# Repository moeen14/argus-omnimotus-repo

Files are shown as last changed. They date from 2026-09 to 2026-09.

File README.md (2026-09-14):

# Argus Omnimotus

Argus Omnimotus is an open-source, modular agricultural robot for autonomy research and robotics education. The platform combines four-wheel independent swerve drive, distributed ESP32 control, multimodal sensing, interchangeable edge computers, and configurable manipulation in a sense-plan-act-verify architecture.

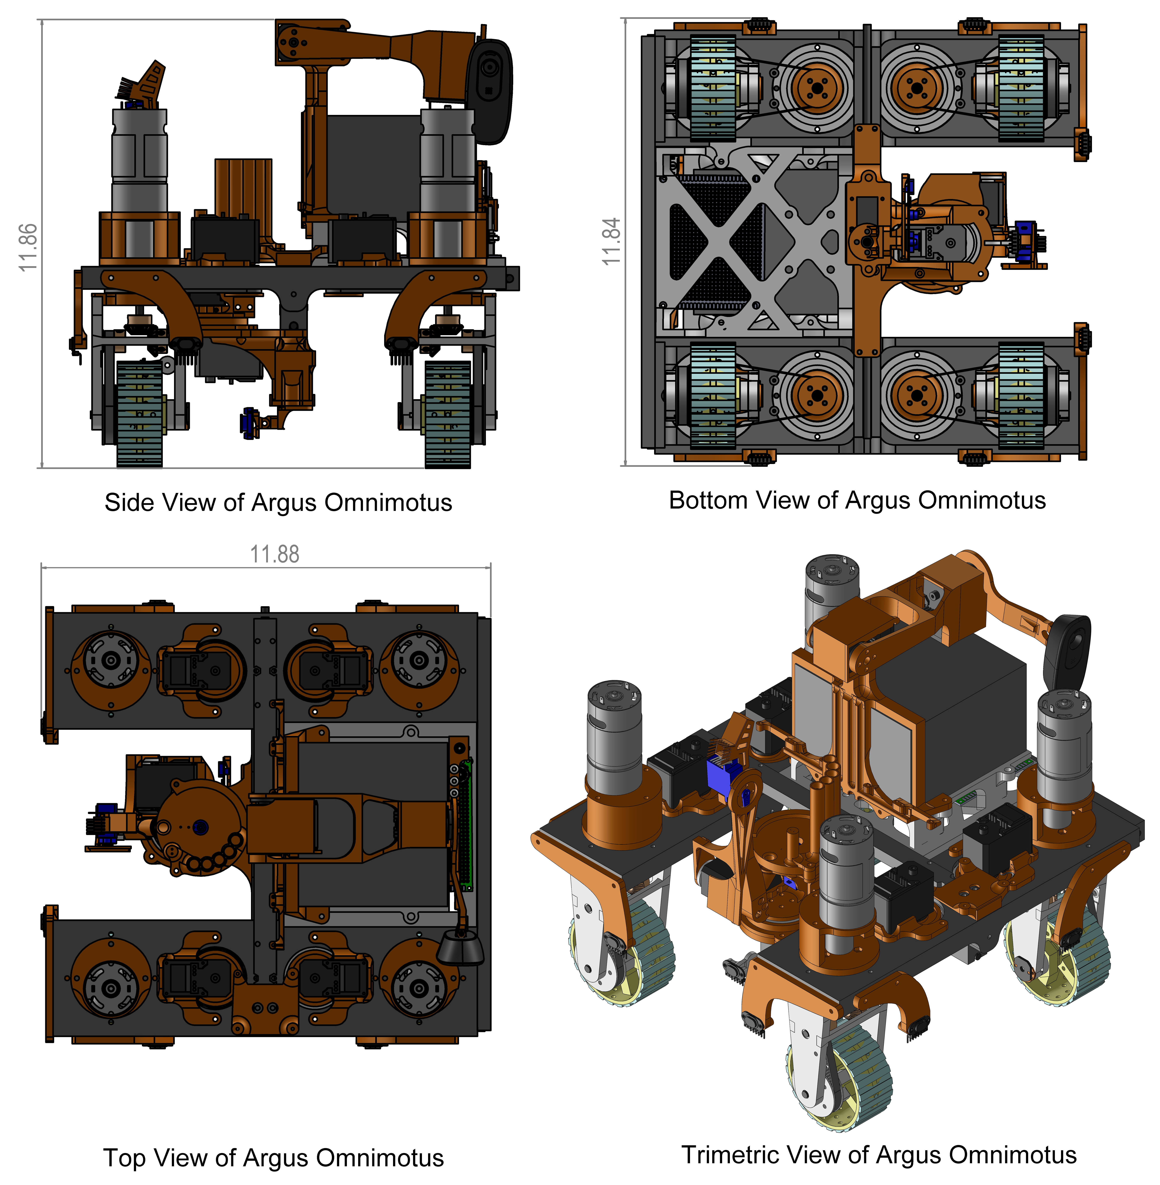
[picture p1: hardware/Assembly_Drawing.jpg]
Argus Omnimotus assembly views


## Repository structure

```text
argus-omnimotus-repo/
|-- applications/   Five complete robot applications
|-- tuning/         Isolated hardware and controller tests
|-- firmware/       ESP32 sensor-board and motion-board firmware
|-- hardware/       CAD, assembly drawing, circuit diagram, BOM and pin map
|-- vision/         Standalone Jetson vision programs
|-- deployment/     Pi 5, Hailo-8 and Jetson deployment tools
|-- models/         Model manifest and Hugging Face download/build utility
|-- docs/           Setup, operation and protocol documentation
|-- tools/          Application, firmware and model launchers
`-- tests/          Hardware-independent repository tests
```

## Main applications

| Command | Program | Purpose |
|---|---|---|
| `dashboard` | `applications/operator_dashboard.py` | Operator dashboard, manual control and telemetry |
| `identify` | `applications/crop_identification.py` | Bottom-camera crop and platform identification |
| `navigate` | `applications/navigate_testbed.py` | Testbed navigation without crop actuation |
| `field` | `applications/field_tasks.py` | Full-field navigation and actuation |
| `lane` | `applications/single_lane_tasks.py` | Repeated navigation and tasks on one lane |

The complete application guide, including optional task verification, is in [docs/programs.md](docs/programs.md). Component-level programs are listed in [tuning/README.md](tuning/README.md).

## Build and run

1. Review the [hardware files](hardware/README.md) and assemble the platform.
2. Build and flash both ESP32 boards using [docs/firmware.md](docs/firmware.md).
3. Configure the Jetson using [docs/jetson-setup.md](docs/jetson-setup.md).
4. Obtain the ONNX weights using [models/README.md](models/README.md), then build TensorRT engines on the Jetson.
5. Copy and edit the robot configuration, complete [calibration](docs/bring-up.md), and launch an application.

```bash
cp robot.example.json robot.json
python tools/run.py --dry-run dashboard
python tools/run.py dashboard
```

The software defaults match the original platform. Confirm device paths, steering angles, wheel directions, camera geometry, controller gains, and mission settings before operating another build.

## Vision deployment

| Target | Backend | Guide |
|---|---|---|
| Raspberry Pi 5 | NCNN | [deployment/raspberry-pi-5.md](deployment/raspberry-pi-5.md) |
| Raspberry Pi 5 with Hailo-8 | HailoRT | [deployment/raspberry-pi-5-hailo8.md](deployment/raspberry-pi-5-hailo8.md) |
| Jetson Orin Nano | TensorRT | [deployment/jetson-orin-nano.md](deployment/jetson-orin-nano.md) |

These targets share the inference evaluator in `deployment/tools/`. The complete autonomous robot applications use the Jetson TensorRT/CUDA implementation. Download the [vision models](https://huggingface.co/moeen14/argus-omnimotus-vision-models) and [labeled evaluation dataset](https://huggingface.co/datasets/moeen14/argus-omnimotus-vision-dataset) from Hugging Face.

## Citation

Please cite the project using [CITATION.cff](CITATION.cff). Contributions are described in [CONTRIBUTING.md](CONTRIBUTING.md).

## License

Argus Omnimotus is released under the [MIT License](LICENSE).

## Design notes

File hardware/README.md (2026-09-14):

# Hardware

This directory contains the mechanical model, assembly drawing, system circuit diagram, component list, and firmware-derived ESP32 pin assignments.

## Files

| File | Description |
|---|---|
| [Argus_Omnimotus_Master_Multibody.SLDPRT](Argus_Omnimotus_Master_Multibody.SLDPRT) | Editable SolidWorks multibody CAD model |
| [Assembly_Drawing.jpg](Assembly_Drawing.jpg) | Side, bottom, top, and trimetric assembly views |
| [Circuit_Diagram.png](Circuit_Diagram.png) | Computing, sensing, actuation, communication, and power architecture |
| [BOM.csv](BOM.csv) | Machine-readable component list |
| [Pin_Map.md](Pin_Map.md) | GPIO, bus, address, and servo-ID assignments from the firmware |

## Assembly drawing

Argus Omnimotus assembly drawing

## Circuit diagram

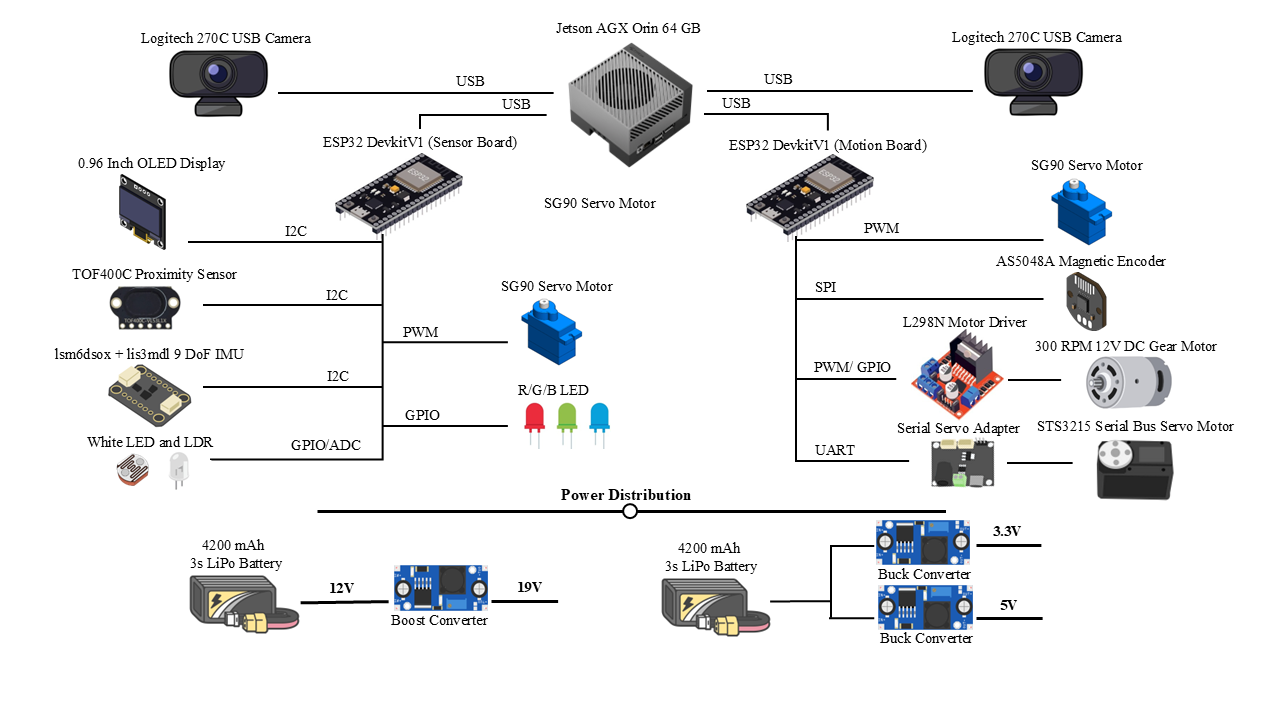
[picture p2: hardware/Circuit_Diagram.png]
Argus Omnimotus circuit diagram


The circuit diagram presents the system-level connections. Use [Pin_Map.md](Pin_Map.md) and the two sketches in [`firmware/`](../firmware/) for implemented GPIO assignments and serial commands. Board 01 handles the wheel encoders in the released firmware, while Board 02 handles the dispenser LDR.

The chassis is primarily 3D-printed PLA reinforced by two 5 mm steel rods. Open the `.SLDPRT` file in SolidWorks to access the editable bodies. The CAD file is stored using Git LFS.

[Return to repository overview](../README.md)

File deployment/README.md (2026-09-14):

# Choose a deployment target

| Target | Vision backend | Start here |
|---|---|---|
| Raspberry Pi 5 CPU | NCNN `.param` + `.bin` | [Pi 5](raspberry-pi-5.md) |
| Raspberry Pi 5 + Hailo-8 | HailoRT `.hef` | [Pi 5 + Hailo-8](raspberry-pi-5-hailo8.md) |
| Jetson Orin Nano | TensorRT `.engine` | [Orin Nano](jetson-orin-nano.md) |

All three use `launch_vision.py` and the shared evaluator. It runs inference on labeled dataset images and writes metrics. Individual live-camera TensorRT utilities are in [vision](../vision/README.md).

The five robot applications use the [robot launcher](../docs/programs.md). Dashboard control uses serial, Tkinter and OpenCV; identification and autonomous applications use TensorRT/PyCUDA. The Pi and Hailo paths provide vision evaluation, while full autonomous control uses the Jetson implementation.

[Model weights](https://huggingface.co/moeen14/argus-omnimotus-vision-models) and the [labeled evaluation dataset](https://huggingface.co/datasets/moeen14/argus-omnimotus-vision-dataset) are distributed through Hugging Face. Keep benchmark assets separate from runtime assets: the benchmark crop model has three classes, while the robot crop model has four.

[Repository home](../README.md)

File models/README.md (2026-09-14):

# Vision assets

[Repository home](../README.md) · [Vision deployment](../deployment/README.md)

Model binaries are distributed through the [Argus Omnimotus model repository](https://huggingface.co/moeen14/argus-omnimotus-vision-models). The [labeled evaluation dataset](https://huggingface.co/datasets/moeen14/argus-omnimotus-vision-dataset) is available separately. This directory contains the SHA-256 and size manifest for the six ONNX files used by the project. Download the files into this directory before verification and engine building.

```bash
python -m pip install -r requirements-models.txt
python tools/models.py download --repo-id moeen14/argus-omnimotus-vision-models --revision main
python tools/models.py verify
python tools/models.py build
```

The download command checks every file against `manifest.json`. `build` runs `trtexec --fp16` on the target Jetson. Use `--directory` for another asset folder and set the same folder in `robot.json`. Repeat `--model FILENAME.onnx` to select individual models.

| ONNX file | Role |
|---|---|
| `crop_detector.onnx` | Bottom-camera crop/platform identification |
| `highcam_platform.onnx` | Overhead platform/ball verification |
| `highcam_rail.onnx` | Current rail segmentation and BEV lane following |
| `lanesegyv8.onnx` | Earlier lane segmentation utilities |
| `resnet18_image_encoder.onnx` | Optional NanoSAM image encoder |
| `mobile_sam_mask_decoder.onnx` | Optional NanoSAM decoder, kept as ONNX |

The field task needs rail and crop engines, plus the overhead platform engine when `--verification on` is selected. NanoSAM is optional. The decoder is excluded from TensorRT building because the existing NanoSAM script runs it with ONNX Runtime. TensorRT engines depend on the target environment; see [NVIDIA's compatibility documentation](https://docs.nvidia.com/deeplearning/tensorrt/latest/getting-started/support-matrix.html). Engine builds and inference must be verified on the target Jetson.

The runtime crop detector uses four classes: `gCrop`, `platform`, `ycrop`, `servo`. The overhead detector uses `ball`, `gcrop`, `platform`, `ycrop`. The separate edge benchmark export declares only three crop-detector classes. Do not substitute benchmark models for robot models based on matching filenames.

The Hugging Face model and dataset cards document class order, preprocessing, release contents, scope, attribution, and licensing. Model downloads use the [Hugging Face Hub API](https://huggingface.co/docs/huggingface_hub/guides/download).

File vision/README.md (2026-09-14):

# Vision utilities

Standalone camera tools are separate from the five robot applications. Launch these through `tools/run.py` so model filenames resolve in the configured model folder:

```bash
python tools/run.py vision/crop_detector_cli.py
python tools/run.py vision/platform_detector_cli.py
python tools/run.py vision/rail_detector.py
```

These use the Jetson TensorRT/PyCUDA environment. `rail_detector_cu.py` is the CuPy variant; `nanosam_cli.py` uses an encoder engine and ONNX decoder. Earlier lane utilities and the distinct crop detector variant remain available for reproduction.

[Model downloads and builds](../models/README.md) | [Pi 5 / Hailo-8 / Orin Nano deployment](../deployment/README.md) | [Main applications](../docs/programs.md)

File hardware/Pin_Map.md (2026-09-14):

# Firmware-derived wiring reference

[Hardware overview](README.md) · [Firmware setup](../docs/firmware.md)

This pin map is extracted from the released firmware. All numbers below are ESP32 GPIO numbers, not DevKit header positions.

## Board 01: sensors

| Interface | GPIO / address |
|---|---|
| Shared I2C | SDA 21, SCL 22, 100 kHz |
| Encoder SPI | SCK 18, MISO 19, MOSI 23 |
| Encoder chip selects, BR / FR / BL / FL | 5 / 4 / 33 / 32 |
| ToF XSHUT, FRS / BRS / BLS / FLF / FLS / CAM / FRF | 13 / 14 / 16 / 17 / 25 / 26 / 27 |
| Corresponding ToF I2C addresses | 0x30 / 0x31 / 0x32 / 0x33 / 0x34 / 0x35 / 0x36 |
| Distal SG90 | 15; 50 Hz, 500–2500 μs; initial angle 180° |
| OLED | I2C, 0x3C, 128 × 64 |
| LSM6DSOX and LIS3MDL | Shared I2C bus |

`CAM` is the firmware's ToF channel label. It is not a camera data connection. Both USB cameras connect directly to the Jetson.

## Board 02: actuators

| Interface | GPIO |
|---|---|
| Bus-servo UART2 | RX 16, TX 17; connect through the appropriate bus-servo interface |
| L298N 1 IN1 / IN2 / IN3 / IN4 | 32 / 33 / 13 / 14 |
| L298N 1 ENA / ENB | 25 / 26 |
| L298N 2 IN1 / IN2 / IN3 / IN4 | 4 / 5 / 18 / 19 |
| L298N 2 ENA / ENB | 21 / 22 |
| RGB red / green / blue | 23 / 15 / 2 |
| Dispenser SG90 | 27 |
| Dispenser LDR | 35 |

Drive PWM is 1 kHz, 8-bit. Motors and serial motion commands use BR, FR, BL, FL order. Bus-servo IDs map as follows:

| ID | Mechanism |
|---|---|
| 1 / 2 / 3 / 4 | BR / FR / FL / BL wheel steering |
| 5 / 6 | Horizontal / vertical arm motion |
| 7 | Bottom camera |
| 8 / 9 | Overhead camera pan / height |

The original deployment note counted only IDs 5–9; the firmware controls **nine** bus servos. GPIO 15 appears on both boards for different functions; that is not a same-board conflict.

The released firmware assigns the **wheel encoders to Board 01** and the **dispenser LDR to Board 02**. These firmware assignments govern the GPIO connections.

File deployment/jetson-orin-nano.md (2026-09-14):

# Jetson Orin Nano

Install the board firmware and JetPack using [NVIDIA's Orin Nano setup guide](https://developer.nvidia.com/embedded/learn/jetson-orin-nano-devkit-user-guide/software_setup.html). For this source, use a JetPack 6 / TensorRT 10 environment compatible with the [recorded Jetson stack](../docs/jetson-setup.md), rather than assuming the newest major release preserves its APIs.

Follow the Python, serial, and camera setup in that guide. Build TensorRT engines on the target Nano and check memory use and control-loop timing before driving.

## Robot applications

```bash
python tools/models.py verify
python tools/models.py build --model crop_detector.onnx --model highcam_rail.onnx --model highcam_platform.onnx
python tools/run.py --dry-run dashboard
python tools/run.py dashboard
```

Supply the ONNX files first using the [model download guide](../models/README.md). Finish [bring-up and calibration](../docs/bring-up.md) before launching `navigate`, `field` or `lane`. Run only one serial-owning application at a time.

## Vision evaluation

Use the **benchmark** ONNX export and dataset, not the robot crop-model manifest. Create an FP16 engine on the Nano:

```bash
/usr/src/tensorrt/bin/trtexec --onnx=/path/to/platform.onnx --saveEngine=/path/to/platform.engine --fp16
python deployment/launch_vision.py orin-nano --check
python deployment/launch_vision.py orin-nano --model /path/to/platform.engine --data /path/to/platform-dataset --task highcam_platform --onnx-ref /path/to/platform.onnx
```

The evaluator additionally uses `onnx` for model metadata. Optional INT8 calibration is in `deployment/tools/build_tensorrt.py`. Build engines on the target device because serialized TensorRT engines are environment-specific.

[Deployment targets](README.md)

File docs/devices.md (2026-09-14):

# Stable serial and camera names

Use `/dev/serial/by-id` and `/dev/v4l/by-id` paths in `robot.json` where available. Identify boards one at a time so sensor and actuator assignments are unambiguous.

If both ESP32 USB adapters report the same serial number, inspect physical connection attributes:

```bash
udevadm info --attribute-walk --name=/dev/ttyUSB0
udevadm info --attribute-walk --name=/dev/ttyUSB1
```

Create `/etc/udev/rules.d/99-argus-esp32.rules` using the actual `KERNELS` USB topology value associated with each adapter. The following is a template, not an installable rule until the placeholders are replaced:

```text
SUBSYSTEM=="tty", KERNELS=="SENSOR_USB_PATH", ATTRS{idVendor}=="10c4", ATTRS{idProduct}=="ea60", SYMLINK+="esp32_01"
SUBSYSTEM=="tty", KERNELS=="ACTUATOR_USB_PATH", ATTRS{idVendor}=="10c4", ATTRS{idProduct}=="ea60", SYMLINK+="esp32_02"
```

The VID/PID above are from the exported robot's CP210x adapters; check yours. Reload with `sudo udevadm control --reload-rules`, then reconnect the boards. Topology aliases change meaning if cables move between hub ports. Confirm identities before enabling actuator power.

[Jetson setup](jetson-setup.md) | [Wiring](../hardware/Pin_Map.md)

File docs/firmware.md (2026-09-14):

# ESP32 DevKit firmware

[Repository home](../README.md) | [Wiring reference](../hardware/Pin_Map.md)

The build target is the classic ESP32 DevKit (`esp32:esp32:esp32`, Arduino's ESP32 Dev Module profile). Confirm flash/board settings for your specific DevKit; ESP32-S3/C3 are different targets.

Install [Arduino CLI](https://arduino.github.io/arduino-cli/) and Python 3.10 or later. From the repository root:

```bash
python tools/firmware.py install
python tools/firmware.py compile
arduino-cli board list
python tools/firmware.py upload --board board01 --port /dev/ttyUSB0
python tools/firmware.py upload --board board02 --port /dev/ttyUSB1
```

Substitute the actual ports, such as `COM5` on Windows. Close serial monitors and control programs before uploading. Uploading compiles first and requires an explicit board and port; it never guesses which board to flash. Each sketch can also be opened in Arduino IDE from its same-named directory.

Core and library versions are defined in `tools/firmware.py`: ESP32 core 3.3.0; ESP32Servo 3.0.9; VL53L1X 1.3.1; Adafruit LSM6DS 4.7.4, LIS3MDL 1.2.4, Unified Sensor 1.1.15, SSD1306 2.5.15, GFX 1.12.6 and BusIO 1.17.4; and SCServo 1.0.2.

Board 02 uses the pin-based LEDC API introduced in [Arduino ESP32 3.x](https://docs.espressif.com/projects/arduino-esp32/en/latest/migration_guides/2.x_to_3.0.html). Core 2.x is unsuitable without porting those calls.

Board 01 identifies as `board01_final_v4`; Board 02 as `board02_final_v10`. Serial communication is newline-terminated ASCII at 921600 baud. See [protocol](protocol.md) and [calibration](bring-up.md).

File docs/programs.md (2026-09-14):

# Main applications

Run commands from the repository root after completing [setup](jetson-setup.md), [model deployment](../models/README.md), and [calibration](bring-up.md). Edit `robot.json` first. Launcher options go before the application name.

| Application | Launch command | Original source |
|---|---|---|
| Operator dashboard | `python tools/run.py dashboard` | `robot/main.py` |
| Crop identification | `python tools/run.py identify` | `robot/identification.py` |
| Navigation without crop tasks | `python tools/run.py navigate` | `Tests/navigation_test.py` |
| Full-field navigation and tasks | `python tools/run.py field` | `Tests/main_task.py` |
| Repeated single-lane tasks | `python tools/run.py lane` | `Tests/lane_platform_alignment_test.py` |

The five primary programs are located directly in `applications/` with names that describe their roles.

## Optional field verification

```bash
python tools/run.py --verification on field
python tools/run.py --verification off field
python tools/run.py --dry-run --verification on field
```

Verification means the existing camera-based ball-placement check after dispensing, including its camera repositioning and retry behavior. It does not disable or enable every sensor feedback check in the controller. The original default remains **off**. When off, the verification TensorRT engine is not loaded; rail and crop engines are still required. The switch applies only to `field` and its compatibility alias `autonomy`.

You can also set `ASABE_ENABLE_BALL_VERIFY` to `1` or `0` in the config's environment dictionary. The command-line flag overrides that setting. `autonomy` remains an alias for `field` so older commands still work.

## Before motion

The dashboard is a local Tkinter interface; the identification and autonomous programs use camera windows and TensorRT. Applications can reposition mechanisms at startup. Run only one application owning the serial ports at a time. Navigation without crop actuation still steers wheels and positions cameras.

Use a dry run to inspect configuration without opening hardware. Test a short controlled sequence after calibration before a complete field run. Mission geometry and controller gains remain in the application source; the launcher does not make the original testbed parameters universal.

[Component tuning](../tuning/README.md) ? [Vision deployment](../deployment/README.md) ? [Repository home](../README.md)

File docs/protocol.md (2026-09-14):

# Serial protocol

[Firmware](firmware.md) | [Wiring](../hardware/Pin_Map.md)

Each board uses USB serial at 921600 baud. Send ASCII commands terminated by a newline. Responses, telemetry and asynchronous completion messages may interleave; clients must parse records rather than assume the next line answers the last command. The sketches remain the complete protocol specification.

## Board 01

Streams `RPM`, `TOF` and `IMU` records. Startup/status messages include firmware and sensor initialization state. OLED commands include `I`, `T`, `T0`, `G`, `B`, `R` and `Z`; `F` resets ToF initialization. `SG90,<angle>` positions the board's SG90. Use the dashboard's existing parser and message handling as the reference client.

## Board 02

| Command | Meaning |
|---|---|
| `P` | Request `POS` for servos 1–9 |
| `MODE,initial,BR,FR,BL,FL` | Apply explicit steering targets; mode may also be `mid` or `perpendicular` |
| `I`, `M`, `T` | Legacy initial, mid, perpendicular presets |
| `F<pwm>`, `B<pwm>` | Forward/reverse in initial mode |
| `L<pwm>`, `R<pwm>` | Lateral movement in perpendicular mode |
| `CW<pwm>`, `CCW<pwm>` | Rotation in mid mode |
| `Fbr,fr,bl,fl` and analogous motion commands | Individual wheel PWM values |
| `DR<delta>`, `DL<delta>`, `DF<delta>`, `DB<delta>` | Mode-dependent steering adjustment |
| `X` | Stop drive motors |
| `5 <angle>` through `9 <angle>` | Position a mechanism servo |
| `G`, `B`, `R` | RGB indication |
| `Z` | Startup RGB sequence |
| `D` | One dispenser cycle |
| `D0`, `RESET` | Reset dispenser memory / empty flags |
| `STATUS`, `L`, `A` | Dispenser state, LDR read, toggle LDR stream |
| `S<angle>`, `STEST` | Dispenser SG90 positioning / sweep |

Bare `B`, `R` and `L` have different meanings from movement commands with numeric payloads. Motion is gated by the current swerve mode. Steering command order is BR, FR, BL, FL, which differs from physical servo ID order 1, 2, 3, 4.

Servos 5–9 produce `ACK,SERVO,...` on command acceptance and unsolicited `DONE,<id>,<reason>` when the motion ends. A `timeout` reason is not proof that the target was reached. The firmware move timeout is 4000 ms. Preserve this distinction when extending plan–act–sense–verify behavior.

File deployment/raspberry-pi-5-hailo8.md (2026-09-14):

# Raspberry Pi 5 + Hailo-8

Install the accelerator and the compatible Raspberry Pi OS/HailoRT stack using the [official Raspberry Pi AI software instructions](https://www.raspberrypi.com/documentation/computers/ai.html). Hailo-8/8L hardware uses `hailo-all`; the AI HAT+ 2 has a different accelerator/software stack and is not this target.

```bash
sudo apt update
sudo apt install hailo-all python3-venv
sudo reboot
```

After reboot, activate a Python 3.10–3.12 environment that can see the system HailoRT bindings. The imported evaluator uses `InferVStreams`; verify that API exists in the installed HailoRT version:

```bash
hailortcli fw-control identify
python3 -m venv --system-site-packages .venv-hailo
source .venv-hailo/bin/activate
python -m pip install -r deployment/requirements-hailo.txt
python deployment/launch_vision.py pi5-hailo8 --check
python deployment/launch_vision.py pi5-hailo8 --model /path/to/platform.hef --data /path/to/platform-dataset --task highcam_platform --onnx-ref /path/to/platform.onnx
```

Obtain a **Hailo-8** HEF from the matching Hugging Face model release; Hailo-8L is a different compilation target. To compile an ONNX model, use the Hailo Dataflow Compiler on its supported build host:

```bash
python deployment/tools/hailo_compile.py --onnx /path/to/platform.onnx --calib /path/to/platform-dataset/images --nc 4 --arch hailo8 --out /path/to/hailo-output
```

The compiler needs its vendor SDK; installing HailoRT on the Pi alone does not supply it. The shared evaluator expects the exported YOLO output layout used by this project. HEFs with embedded NMS may require decoder changes.

[Deployment targets](README.md)

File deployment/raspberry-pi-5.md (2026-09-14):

# Raspberry Pi 5: CPU vision

Use 64-bit Raspberry Pi OS with Python 3.10–3.12 (Bookworm/Python 3.11 is a suitable environment for these package pins). Create an environment separate from the robot dashboard:

```bash
sudo apt install python3-venv libgl1 libglib2.0-0
python3 -m venv .venv-vision
source .venv-vision/bin/activate
python -m pip install -r deployment/requirements-cpu.txt
python deployment/launch_vision.py pi5 --check
```

Obtain matching NCNN `.param` and `.bin` files plus labeled benchmark images from the project's Hugging Face release:

```bash
python deployment/launch_vision.py pi5 --model /path/to/platform.param --data /path/to/platform-dataset --task highcam_platform --onnx-ref /path/to/platform.onnx
```

For conversion, use `deployment/tools/ncnn_compile.py` on a build host with pnnx and the NCNN conversion tools:

```bash
python deployment/tools/ncnn_compile.py --onnx /path/to/platform.onnx --calib /path/to/platform-dataset/images --out /path/to/ncnn-output --tools /path/to/ncnn-tools --pnnx /path/to/pnnx
```

The converter creates the backend assets; it does not train the model. NCNN build instructions are maintained by [Tencent/NCNN](https://github.com/Tencent/ncnn/wiki/how-to-build).

[Deployment targets](README.md)

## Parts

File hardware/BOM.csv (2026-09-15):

category | quantity | component | role
Computing | 1 | NVIDIA Jetson AGX Orin 64 GB | High-level perception planning and supervision
Embedded control | 2 | ESP32 DevKit V1 | Sensor and motion controllers
Vision | 2 | Logitech C270 USB camera | Bottom and overhead vision
Range sensing | 7 | VL53L1X-compatible ToF module | Navigation and alignment ranging
Inertial sensing | 1 | LSM6DSOX and LIS3MDL 9-DoF IMU | Acceleration angular rate and magnetic sensing
Wheel feedback | 4 | AS5048A magnetic encoder | Wheel rotation sensing
Display | 1 | 0.96-inch SSD1306 I2C OLED | Local status display
Drive | 4 | 300 RPM 12 V DC gearmotor | Wheel propulsion
Drive electronics | 2 | L298N dual H-bridge motor driver | DC motor control
Steering and mechanisms | 9 | STS3215 serial bus servo | Four steering axes and five mechanism axes
Servo interface | 1 | Serial bus servo adapter | ESP32-to-STS servo interface
Auxiliary actuation | 2 | SG90 micro servo | Distal flap and dispenser
Task sensing | 1 | LDR and white LED | Dispenser state sensing
Status | 1 | RGB LED | Robot state indication
Battery | 2 | 4200 mAh 3S LiPo battery | Robot power
Power conversion | 1 | Boost converter | 19 V rail
Power conversion | 2 | Buck converter | 5 V and 3.3 V rails
Structure | 1 set | 3D-printed PLA chassis | Robot frame and mechanisms
Structure | 3 | 5 mm steel rod | Chassis reinforcement

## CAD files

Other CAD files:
hardware/Argus_Omnimotus_Master_Multibody.SLDPRT

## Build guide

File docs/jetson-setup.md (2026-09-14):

# Jetson setup

[Repository home](../README.md) | [Hardware](../hardware/README.md)

## Reference environment

The reference platform used Jetson AGX Orin 64 GB, Ubuntu 22.04.5, L4T 36.4.7, Python 3.10.12, CUDA 12.6, cuDNN 9.3, and TensorRT 10.7.0.23.

Install a compatible NVIDIA JetPack/L4T image and its CUDA/TensorRT development packages using [NVIDIA's Jetson documentation](https://docs.nvidia.com/jetson/). Retain the system TensorRT Python bindings.

## Python environment

Run these commands on the Jetson from this repository's root:

```bash
sudo apt update
sudo apt install python3-venv python3-dev python3-tk python3-opencv build-essential v4l-utils
python3 -m venv --system-site-packages .venv
source .venv/bin/activate
python -m pip install -r requirements.txt
python -m pip install pycuda==2026.1
python -c "import cv2, numpy, serial, tkinter, tensorrt, pycuda.driver; print(tensorrt.__version__); print(cv2.__version__)"
```

PyCUDA needs the installed CUDA headers/compiler; ensure `/usr/local/cuda/bin` is on PATH when building it. The reference environment had NumPy 1.26.4 and PySerial 3.5. OpenCV must have GUI support for the camera windows; do not replace it with a headless wheel in this environment. Utilities using ArUco also require `cv2.aruco`.

Only the optional CuPy vision utility needs `cupy-cuda12x==13.6.0`. NanoSAM and the ONNX class viewer need a Jetson-compatible ONNX Runtime installation; NanoSAM expects its CUDA execution provider. Use the NVIDIA/ONNX Runtime build appropriate to this JetPack version and verify providers with `onnxruntime.get_available_providers()`. These GPU packages are separate from the generic requirements file. Torch is not required for the TensorRT autonomy task.

## Device configuration

```bash
ls -l /dev/serial/by-id/
v4l2-ctl --list-devices
ls -l /dev/v4l/by-id/
cp robot.example.json robot.json
sudo usermod -aG dialout,video "$USER"
```

Log out and back in after changing groups. Edit `robot.json` with stable device paths. The `/dev/video0` and `/dev/video2` values are examples; camera indexes vary. Board 01 is the sensor board; Board 02 is the actuator board. Both use 921600 baud. When USB serial identities are identical, assign stable udev aliases using each board's physical USB path, following [device naming](devices.md).

The launcher passes configured `ASABE_*` environment variables to each program and runs it with the model directory as its working directory. Values in the JSON override shell values. An explicitly supplied engine environment variable overrides the launcher's model-directory default; use absolute engine paths.

The dashboard and OpenCV displays require a graphical session. The remote keyboard client forwards keys to the running dashboard; it does not create a browser interface. Keep its listener on localhost and use an SSH tunnel for remote access.

Continue with [firmware](firmware.md), [models](../models/README.md), then [bring-up](bring-up.md).

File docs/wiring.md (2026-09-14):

# Firmware-derived wiring reference

[Hardware and CAD](../hardware/README.md) · [Firmware setup](firmware.md)

This pin map is extracted from the packaged firmware. It is a signal reference, not a complete power, connector or protection schematic. All numbers below are ESP32 GPIO numbers, not DevKit header positions.

## Board 01: sensors

| Interface | GPIO / address |
|---|---|
| Shared I2C | SDA 21, SCL 22, 100 kHz |
| Encoder SPI | SCK 18, MISO 19, MOSI 23 |
| Encoder chip selects, BR / FR / BL / FL | 5 / 4 / 33 / 32 |
| ToF XSHUT, FRS / BRS / BLS / FLF / FLS / CAM / FRF | 13 / 14 / 16 / 17 / 25 / 26 / 27 |
| Corresponding ToF I2C addresses | 0x30 / 0x31 / 0x32 / 0x33 / 0x34 / 0x35 / 0x36 |
| Distal SG90 | 15; 50 Hz, 500–2500 μs; initial angle 180° |
| OLED | I2C, 0x3C, 128 × 64 |
| LSM6DSOX and LIS3MDL | Shared I2C bus |

`CAM` is the firmware's ToF channel label. It is not a camera data connection. Both USB cameras connect directly to the Jetson.

## Board 02: actuators

| Interface | GPIO |
|---|---|
| Bus-servo UART2 | RX 16, TX 17; connect through the appropriate bus-servo interface |
| L298N 1 IN1 / IN2 / IN3 / IN4 | 32 / 33 / 13 / 14 |
| L298N 1 ENA / ENB | 25 / 26 |
| L298N 2 IN1 / IN2 / IN3 / IN4 | 4 / 5 / 18 / 19 |
| L298N 2 ENA / ENB | 21 / 22 |
| RGB red / green / blue | 23 / 15 / 2 |
| Dispenser SG90 | 27 |
| Dispenser LDR | 35 |

Drive PWM is 1 kHz, 8-bit. Motors and serial motion commands use BR, FR, BL, FL order. Bus-servo IDs map as follows:

| ID | Mechanism |
|---|---|
| 1 / 2 / 3 / 4 | BR / FR / FL / BL wheel steering |
| 5 / 6 | Horizontal / vertical arm motion |
| 7 | Bottom camera |
| 8 / 9 | Overhead camera pan / height |

The original deployment note counted only IDs 5–9; the firmware controls **nine** bus servos. GPIO 15 appears on both boards for different functions; that is not a same-board conflict.

The manuscript's board ownership descriptions differ from the source for the wheel encoders and dispenser LDR. This release follows the firmware: **encoders on Board 01, LDR on Board 02**. Verify the physical harness and reconcile the final circuit drawing before publishing it as a build specification.

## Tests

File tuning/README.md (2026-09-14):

# Component tuning and isolated tests

These programs calibrate or test individual activities. They are separate from the five [main applications](../docs/programs.md). They may move real hardware; do not run them through unit-test discovery.

Launch from the repository root using the shared configuration:

```bash
python tools/run.py tuning/motor_threshold_test.py
python tools/run.py tuning/servo_dashboard_test.py
python tools/run.py keyboard
```

Some utilities expose their own port/camera arguments or source constants; environment configuration applies only where supported. Inspect these before running a utility. Do not assume an older program?s `--help` is hardware-free.

| Utility | Purpose |
|---|---|
| `ball_dispense_test.py` | Ball dispense |
| `bottom_cam_crop_detector_test.py` | Bottom cam crop detector |
| `crop_detector_area_test.py` | Crop detector area |
| `dual_usb_camera_viewer.py` | Dual usb camera viewer |
| `esp_serial_sender.py` | Esp serial sender |
| `front_cam_TOF_alignment_test.py` | Front cam tof alignment |
| `interlane_forward_test.py` | Interlane forward |
| `lane_alignment_test.py` | Lane alignment |
| `motor_threshold_test.py` | Motor threshold |
| `overhead_cam_highcam_platform_test.py` | Overhead cam highcam platform |
| `platform_alignment_test.py` | Platform alignment |
| `remote_keyboard.py` | Remote keyboard |
| `servo_dashboard_test.py` | Servo dashboard |
| `teleop_image_capture.py` | Teleop image capture |
| `tof_rail_alignment.py` | Tof rail alignment |
| `tof_turnaround_tuner.py` | Tof turnaround tuner |
| `topple_drop_test.py` | Topple drop |
| `wheel_balancing_test.py` | Wheel balancing |

For whole-field navigation or repeated single-lane tasks, use `navigate`, `field` or `lane` instead of combining these tuning utilities.

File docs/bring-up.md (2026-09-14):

# Bring-up and calibration

1. Check the [circuit diagram and firmware-derived pin map](../hardware/README.md), board roles, and power distribution. Verify the servo supply, motor supply, and common ground before applying power.
2. Flash each DevKit and verify serial identities at 921600 baud. With actuator power isolated, check Board 01's sensor telemetry and both camera feeds.
3. Configure stable serial/camera paths and matching model files. Preview the launch command with `python tools/run.py --dry-run dashboard`.
4. Raise the wheels clear of the ground and keep mechanisms clear before enabling actuator power. Dashboard and task initialization can reposition servos. Keep a physical power disconnect reachable; `X` stops drive motors but is not a complete mechanism emergency stop.
5. Verify wheel order **BR, FR, BL, FL** and individual motor signs. Wheel servo IDs are **1, 2, 4, 3** in that order. Calibrate Board 02's `SAFE_ARCS`, steering preset angles and motor sign arrays to the installed geometry before driving. Do not treat a timed-out servo move as successful arrival.
6. Calibrate camera intrinsics/BEV source points, ToF placement and offsets, wheel encoder directions and motor thresholds. The source settings are for the original platform. Use the individual [programs](programs.md), then validate a short manual movement and stop.
7. Validate crop/platform class ordering with the matched model before enabling closed-loop manipulation. Check single alignment and dispense cycles before running a complete course.
8. Set course, clearance and actuation constants in `applications/field_tasks.py` for your testbed. Launch `python tools/run.py autonomy` only after the component checks pass.

Run one process owning the serial ports at a time. Stop the dashboard before starting autonomy or a hardware test. The scripts do not implement shared serial arbitration.

Controller constants are defined in their application modules. The JSON configuration centralizes device names and model locations.

[Repository home](../README.md) · [Hardware](../hardware/README.md)

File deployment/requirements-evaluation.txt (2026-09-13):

numpy<2
opencv-python-headless
onnx
onnxruntime
pyyaml

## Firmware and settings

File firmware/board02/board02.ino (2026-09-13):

#include <SCServo.h>
#include <math.h>


#define SERIAL_BAUD 921600
#define SERIAL_TIMEOUT_MS 20
#define RXD2 16
#define TXD2 17
#define FW_VERSION "board02_final_v10"

#define L298N1_IN1 32
#define L298N1_IN2 33
#define L298N1_IN3 13
#define L298N1_IN4 14
#define L298N1_ENA 25
#define L298N1_ENB 26

#define L298N2_IN1 4
#define L298N2_IN2 5
#define L298N2_IN3 18
#define L298N2_IN4 19
#define L298N2_ENA 21
#define L298N2_ENB 22

#define LED_RED   23
#define LED_GREEN 15
#define LED_BLUE  2

#define DISPENSER_SERVO_PIN 27
#define DISPENSER_LDR_PIN   35

SMS_STS st;

const int NUM_SERVOS = 9;
const int IDS[NUM_SERVOS] = {1, 2, 3, 4, 5, 6, 7, 8, 9};
const int NUM_MOTORS = 4;
const float SAFE_TOLERANCE_DEG = 5.0f;
const int NUM_SWERVE = 4;
const float MAX_DELTA_DEG = 30.0f;

enum SwerveMode {
  SWERVE_UNKNOWN,
  SWERVE_INITIAL,
  SWERVE_MID,
  SWERVE_PERPENDICULAR
};

SwerveMode currentSwerveMode = SWERVE_UNKNOWN;


const int WHEEL_TO_SWERVE_IDX[NUM_SWERVE] = {0, 1, 3, 2};
float currentSwerveTargets[NUM_SWERVE] = {37.0f, 6.0f, 145.0f, 221.0f};

const char *swerveModeName() {
  if (currentSwerveMode == SWERVE_INITIAL) return "initial";
  if (currentSwerveMode == SWERVE_MID) return "mid";
  if (currentSwerveMode == SWERVE_PERPENDICULAR) return "perpendicular";
  return "unknown";
}


const int DELTA_FORWARD_SIGN[NUM_SWERVE]  = {-1,  -1, -1,  -1};
const int DELTA_BACKWARD_SIGN[NUM_SWERVE] = { 1, 1,  1, 1};
const int DELTA_RIGHT_SIGN[NUM_SWERVE]    = { 1, 1,  1, 1};
const int DELTA_LEFT_SIGN[NUM_SWERVE]     = {-1,  -1, -1,  -1};

const int PWM_FREQ = 1000;
const int PWM_RESOLUTION = 8;
const int MAX_MOTOR_PWM = 255;


const int MOTOR_FORWARD_SIGN[NUM_MOTORS]  = { -1,  1,  1,  1};
const int MOTOR_BACKWARD_SIGN[NUM_MOTORS] = {1, -1, -1, -1};
const int MOTOR_LEFT_SIGN[NUM_MOTORS]     = {1, 1, 1, -1};
const int MOTOR_RIGHT_SIGN[NUM_MOTORS]    = { -1,  -1,  -1,  1};
const int MOTOR_CW_SIGN[NUM_MOTORS]       = {1, -1,  1,  1};
const int MOTOR_CCW_SIGN[NUM_MOTORS]      = { -1,  1, -1, -1};

struct MotorConfig {
  int in1;
  int in2;
  int en;
};

const MotorConfig MOTORS[NUM_MOTORS] = {
  {L298N1_IN1, L298N1_IN2, L298N1_ENA},
  {L298N1_IN3, L298N1_IN4, L298N1_ENB},
  {L298N2_IN1, L298N2_IN2, L298N2_ENA},
  {L298N2_IN3, L298N2_IN4, L298N2_ENB},
};

struct SafeArcConfig {
  const char *name;
  bool safeArcEnabled;
  float startDeg;
  float endDeg;
  int dir;
  float initialDeg;
  float midDeg;
  float perpendicularDeg;
  float leftLookDeg;
  float rightLookDeg;
};

const SafeArcConfig SAFE_ARCS[NUM_SERVOS] = {
  {"BR",             true,  67.0f, 186.0f, -1,  37.0f, 306.0f, 225.0f, -1.0f,  -1.0f},
  {"FR",             true, 335.0f, 216.0f,  1,   6.0f,  96.0f, 180.0f, -1.0f,  -1.0f},
  {"FL",             true, 251.0f,  11.0f, -1, 221.0f, 131.0f,  41.0f, -1.0f,  -1.0f},
  {"BL",             true, 115.0f, 355.0f,  1, 145.0f, 235.0f, 325.0f, -1.0f,  -1.0f},
  {"ArmHorizontal",  true, 295.0f, 345.0f,  1, 321.0f,  -1.0f,  -1.0f, -1.0f,  -1.0f},
  {"ArmVertical",    true,  60.0f, 240.0f, -1,  35.0f,  -1.0f,  -1.0f, -1.0f,  -1.0f},
  {"Camera",         true, 321.0f, 231.0f,  1,  51.0f,  -1.0f,  -1.0f,141.0f, 321.0f},
  {"Servo8",         true, 167.0f,   5.0f,  1, 176.0f,  -1.0f,  -1.0f, -1.0f,  -1.0f},
  {"Servo9",         true,  23.0f, 148.0f,  1,  20.0f,  -1.0f,  -1.0f, -1.0f,  -1.0f},
};

const unsigned long LOOP_DELAY_MS = 10;
const unsigned long LOG_PERIOD_MS = 100;
const unsigned long MOVE_TIMEOUT_MS = 4000;
const bool SERVO_MOVE_LOGS = false;

struct MotionState {
  bool active;
  float requestedTarget;
  float target;
  float startAngle;
  float startErr;
  float lastErr;
  float maxAbsErr;
  float threshold;
  int minSpeed;
  int maxSpeed;
  int acc;
  int lastSpeed;
  unsigned long startMs;
  unsigned long lastLogMs;
  int samples;
  int stableCount;
};

MotionState motion[NUM_SERVOS];

void configureProfile(MotionState &m);
int computeSpeed(const MotionState &m, float err);
float angleError(float target, float current);
float swerveBaseTarget(int idx, SwerveMode mode);
void commandSwerveMode(SwerveMode mode, const char *label);


float normalizeAngle(float angle) {
  angle = fmodf(angle, 360.0f);
  if (angle < 0.0f) angle += 360.0f;
  return angle;
}

float posToAngle(int pos) {
  pos = pos % 4096;
  if (pos < 0) pos += 4096;
  return pos * 360.0f / 4096.0f;
}

float arcDistance(float from, float to, int dir) {
  from = normalizeAngle(from);
  to = normalizeAngle(to);
  if (dir > 0) {
    return fmodf((to - from + 360.0f), 360.0f);
  }
  return fmodf((from - to + 360.0f), 360.0f);
}

float safeArcLength(int idx) {
  if (!SAFE_ARCS[idx].safeArcEnabled) return 360.0f;
  const SafeArcConfig &cfg = SAFE_ARCS[idx];
  return arcDistance(cfg.startDeg, cfg.endDeg, cfg.dir);
}

float safeArcCoordRaw(int idx, float angle) {
  const SafeArcConfig &cfg = SAFE_ARCS[idx];
  return arcDistance(cfg.startDeg, angle, cfg.dir);
}

bool isInSafeArc(int idx, float angle) {
  if (!SAFE_ARCS[idx].safeArcEnabled) return true;
  float coord = safeArcCoordRaw(idx, angle);
  float len = safeArcLength(idx);
  return coord <= (len + SAFE_TOLERANCE_DEG) ||
         coord >= (360.0f - SAFE_TOLERANCE_DEG);
}

float clampToSafeArc(int idx, float angle) {
  angle = normalizeAngle(angle);
  if (!SAFE_ARCS[idx].safeArcEnabled) return angle;
  if (isInSafeArc(idx, angle)) return angle;

  const SafeArcConfig &cfg = SAFE_ARCS[idx];
  float coord = safeArcCoordRaw(idx, angle);
  float len = safeArcLength(idx);
  float distToStart = 360.0f - coord;
  float distToEnd = coord - len;

  return (distToStart < distToEnd) ? cfg.startDeg : cfg.endDeg;
}

float safeArcCoordClamped(int idx, float angle) {
  if (!SAFE_ARCS[idx].safeArcEnabled) return normalizeAngle(angle);
  float coord = safeArcCoordRaw(idx, angle);
  float len = safeArcLength(idx);
  if (coord <= len) return coord;
  if (coord >= (360.0f - SAFE_TOLERANCE_DEG)) return 0.0f;

  float distToStart = 360.0f - coord;
  float distToEnd = coord - len;
  return (distToStart < distToEnd) ? 0.0f : len;
}


float safeArcError(int idx, float target, float current) {
  if (!SAFE_ARCS[idx].safeArcEnabled || safeArcLength(idx) >= 359.0f) {
    return angleError(target, current);
  }

  const SafeArcConfig &cfg = SAFE_ARCS[idx];
  float targetCoord = safeArcCoordClamped(idx, target);
  float currentCoord = safeArcCoordClamped(idx, current);
  return cfg.dir * (targetCoord - currentCoord);
}


float angleError(float target, float current) {
  float err = normalizeAngle(target) - normalizeAngle(current);
  while (err >  180.0f) err -= 360.0f;
  while (err < -180.0f) err += 360.0f;
  return err;
}

int signOf(float value) {
  if (value > 0.0f) return 1;
  if (value < 0.0f) return -1;
  return 0;
}


void setupMotors() {
  for (int i = 0; i < NUM_MOTORS; i++) {
    pinMode(MOTORS[i].in1, OUTPUT);
    pinMode(MOTORS[i].in2, OUTPUT);
    ledcAttach(MOTORS[i].en, PWM_FREQ, PWM_RESOLUTION);
  }
}

void setMotorSigned(int idx, int signedPwm) {
  int pwm = constrain(abs(signedPwm), 0, MAX_MOTOR_PWM);

  if (pwm == 0) {
    digitalWrite(MOTORS[idx].in1, LOW);
    digitalWrite(MOTORS[idx].in2, LOW);
  } else if (signedPwm > 0) {
    digitalWrite(MOTORS[idx].in1, HIGH);
    digitalWrite(MOTORS[idx].in2, LOW);
  } else {
    digitalWrite(MOTORS[idx].in1, LOW);
    digitalWrite(MOTORS[idx].in2, HIGH);
  }

  ledcWrite(MOTORS[idx].en, pwm);
}

void stopMotors(bool acknowledge) {
  for (int i = 0; i < NUM_MOTORS; i++) {
    setMotorSigned(i, 0);
  }

  if (acknowledge) {
    Serial.println("ACK,MOTOR,STOP");
  }
}

void printMotorAck(const char *label, const int pwms[NUM_MOTORS], bool perWheel) {
  Serial.print("ACK,MOTOR,");
  Serial.print(label);
  Serial.print(",");
  if (perWheel) {
    Serial.print("BR=");
    Serial.print(pwms[0]);
    Serial.print(",FR=");
    Serial.print(pwms[1]);
    Serial.print(",BL=");
    Serial.print(pwms[2]);
    Serial.print(",FL=");
    Serial.println(pwms[3]);
  } else {
    Serial.println(pwms[0]);
  }
}

void commandMotors(const char *label, const int pwms[NUM_MOTORS], const int signs[NUM_MOTORS], bool perWheel) {
  int appliedPwms[NUM_MOTORS];
  for (int i = 0; i < NUM_MOTORS; i++) {
    int pwm = constrain(pwms[i], 0, MAX_MOTOR_PWM);
    appliedPwms[i] = pwm;
    setMotorSigned(i, signs[i] * pwm);
  }

  printMotorAck(label, appliedPwms, perWheel);
}

void commandMotors(const char *label, int pwm, const int signs[NUM_MOTORS]) {
  int pwms[NUM_MOTORS] = {pwm, pwm, pwm, pwm};
  commandMotors(label, pwms, signs, false);
}

bool isUnsignedInteger(const String &value) {
  if (value.length() == 0) return false;
  for (int i = 0; i < value.length(); i++) {
    if (!isDigit(value.charAt(i))) return false;
  }
  return true;
}

bool parseMotorPwms(const String &text, int pwms[NUM_MOTORS], bool &perWheel) {
  perWheel = text.indexOf(',') >= 0;

  if (!perWheel) {
    if (!isUnsignedInteger(text)) return false;
    int pwm = text.toInt();
    for (int i = 0; i < NUM_MOTORS; i++) {
      pwms[i] = constrain(pwm, 0, MAX_MOTOR_PWM);
    }
    return true;
  }

  int start = 0;
  for (int i = 0; i < NUM_MOTORS; i++) {
    int comma = text.indexOf(',', start);
    String part;
    if (i == NUM_MOTORS - 1) {
      part = text.substring(start);
      if (comma >= 0) return false;
    } else {
      if (comma < 0) return false;
      part = text.substring(start, comma);
      start = comma + 1;
    }
    part.trim();
    if (!isUnsignedInteger(part)) return false;
    pwms[i] = constrain(part.toInt(), 0, MAX_MOTOR_PWM);
  }

  return true;
}

bool tryHandleMotorCommand(const String &upper) {
  if (upper == "X" || upper == "STOP") {
    stopMotors(true);
    return true;
  }

  if (upper.length() >= 2 && (upper.charAt(0) == 'F' || upper.charAt(0) == 'B' ||
                              upper.charAt(0) == 'L' || upper.charAt(0) == 'R')) {
    char dir = upper.charAt(0);
    String pwmText = upper.substring(1);
    int pwms[NUM_MOTORS];
    bool perWheel = false;
    if (!parseMotorPwms(pwmText, pwms, perWheel)) {
      Serial.println("ERR,MOTOR_PWM");
      return true;
    }

    if ((dir == 'F' || dir == 'B') && currentSwerveMode != SWERVE_INITIAL) {
      stopMotors(false);
      Serial.println("ERR,MOTOR_REJECT,FB_requires_initial_mode");
      return true;
    }

    if ((dir == 'L' || dir == 'R') && currentSwerveMode != SWERVE_PERPENDICULAR) {
      stopMotors(false);
      Serial.println("ERR,MOTOR_REJECT,LR_requires_perpendicular_mode");
      return true;
    }

    const int *signs = MOTOR_FORWARD_SIGN;
    const char *label = "F";
    if (dir == 'B') {
      signs = MOTOR_BACKWARD_SIGN;
      label = "B";
    } else if (dir == 'L') {
      signs = MOTOR_LEFT_SIGN;
      label = "L";
    } else if (dir == 'R') {
      signs = MOTOR_RIGHT_SIGN;
      label = "R";
    }

    commandMotors(label, pwms, signs, perWheel);
    return true;
  }

  bool cwPrefix = upper.startsWith("CW");
  bool ccwPrefix = upper.startsWith("CCW");
  bool cwSuffix = upper.endsWith("CW");
  bool ccwSuffix = upper.endsWith("CCW");

  if (cwPrefix || ccwPrefix || cwSuffix || ccwSuffix) {
    bool ccw = ccwPrefix || ccwSuffix;
    String pwmText;

    if (ccwPrefix) {
      pwmText = upper.substring(3);
    } else if (cwPrefix) {
      pwmText = upper.substring(2);
    } else if (ccwSuffix) {
      pwmText = upper.substring(0, upper.length() - 3);
    } else {
      pwmText = upper.substring(0, upper.length() - 2);
    }

    int pwms[NUM_MOTORS];
    bool perWheel = false;
    if (!parseMotorPwms(pwmText, pwms, perWheel)) {
      Serial.println("ERR,MOTOR_PWM");
      return true;
    }

    if (currentSwerveMode != SWERVE_MID) {
      stopMotors(false);
      Serial.println("ERR,MOTOR_REJECT,CW_CCW_requires_mid_mode");
      return true;
    }

    commandMotors(ccw ? "CCW" : "CW", pwms,
                  ccw ? MOTOR_CCW_SIGN : MOTOR_CW_SIGN, perWheel);
    return true;
  }

  return false;
}


void setupLEDs() {
  pinMode(LED_RED, OUTPUT);
  pinMode(LED_GREEN, OUTPUT);
  pinMode(LED_BLUE, OUTPUT);
  setLEDs(false, false, false);
}

void setLEDs(bool red, bool green, bool blue) {
  digitalWrite(LED_RED, red ? HIGH : LOW);
  digitalWrite(LED_GREEN, green ? HIGH : LOW);
  digitalWrite(LED_BLUE, blue ? HIGH : LOW);
}

void flashLEDColor(bool red, bool green, bool blue, unsigned long durationMs) {
  setLEDs(red, green, blue);
  delay(durationMs);
  setLEDs(false, false, false);
}

void celebrateBootLEDs() {
  for (int i = 0; i < 18; i++) {
    setLEDs(true, false, false);
    delay(45);
    setLEDs(false, true, false);
    delay(45);
    setLEDs(false, false, true);
    delay(45);
    setLEDs(false, false, false);
    delay(25);
  }

  for (int i = 0; i < 14; i++) {
    setLEDs(true, true, true);
    delay(55);
    setLEDs(false, false, false);
    delay(45);
  }

  for (int i = 0; i < 12; i++) {
    setLEDs(true, true, false);
    delay(55);
    setLEDs(false, false, false);
    delay(30);
    setLEDs(false, true, true);
    delay(55);
    setLEDs(false, false, false);
    delay(30);
    setLEDs(true, false, true);
    delay(55);
    setLEDs(false, false, false);
    delay(30);
  }

  for (int i = 0; i < 10; i++) {
    setLEDs(true, false, false);
    delay(35);
    setLEDs(false, false, true);
    delay(35);
    setLEDs(false, true, false);
    delay(35);
    setLEDs(true, true, true);
    delay(45);
    setLEDs(false, false, false);
    delay(35);
  }

  for (int i = 0; i < 8; i++) {
    setLEDs(true, true, true);
    delay(70);
    setLEDs(false, false, false);
    delay(70);
  }
}

bool tryHandleLEDCommand(const String &upper) {
  if (upper == "R") {
    flashLEDColor(true, false, false, 200);
    Serial.println("ACK,LED,R");
    return true;
  }
  if (upper == "G") {
    flashLEDColor(false, true, false, 200);
    Serial.println("ACK,LED,G");
    return true;
  }
  if (upper == "B") {
    flashLEDColor(false, false, true, 200);
    Serial.println("ACK,LED,B");
    return true;
  }
  if (upper == "Z") {


    for (int i = 0; i < NUM_SERVOS; i++) {
      st.WriteSpe(IDS[i], 0, 50);
      motion[i].active = false;
    }
    stopMotors(false);
    celebrateBootLEDs();
    Serial.println("ACK,LED,Z");
    return true;
  }
  return false;
}


const int DISPENSER_SERVO_FREQ_HZ = 50;
const int DISPENSER_SERVO_MIN_US = 500;
const int DISPENSER_SERVO_MAX_US = 2500;
const int DISPENSER_SERVO_PWM_RESOLUTION = 16;
const int DISPENSER_SERVO_PERIOD_US = 1000000 / DISPENSER_SERVO_FREQ_HZ;

const int DISPENSER_NUM_TUBES = 5;
const int DISPENSER_TUBE_START[DISPENSER_NUM_TUBES] = {90, 113, 130, 150, 170};
const int DISPENSER_TUBE_END[DISPENSER_NUM_TUBES]   = {100, 123, 140, 160, 180};
const char *DISPENSER_TUBE_NAMES[DISPENSER_NUM_TUBES] = {
  "TUBE_1",
  "TUBE_2",
  "TUBE_3",
  "TUBE_4",
  "TUBE_5"
};

const int DISPENSER_DROP_START_ANGLE = 15;
const int DISPENSER_DROP_END_ANGLE = 5;
const int DISPENSER_LDR_CHECK_ANGLE = 52;
const int DISPENSER_HOME_ANGLE = DISPENSER_LDR_CHECK_ANGLE;

const int DISPENSER_LDR_SAMPLES = 7;
const int DISPENSER_LDR_BALL_PRESENT_MAX = 2850;
const int DISPENSER_LDR_NO_BALL_MIN = 3000;
const unsigned long DISPENSER_LDR_PRINT_INTERVAL_MS = 250;

const int DISPENSER_PICKUP_TRIES_PER_TUBE = 2;
const int DISPENSER_DROP_RETRY_MAX = 3;
const int DISPENSER_FAST_FINAL_APPROACH_DEG = 8;
const int DISPENSER_FAST_SETTLE_MS = 70;
const int DISPENSER_POSITION_SETTLE_MS = 45;
const int DISPENSER_CAUTIOUS_STEP_DELAY_MS = 12;
const int DISPENSER_TUBE_SWEEP_DELAY_MS = 20;
const int DISPENSER_DROP_SWEEP_DELAY_MS = 35;
const int DISPENSER_LDR_SETTLE_MS = 1000;

int dispenserCurrentAngle = DISPENSER_HOME_ANGLE;
bool dispenserServoAttached = false;
bool dispenserAutoLdr = false;
bool dispenserTubeEmpty[DISPENSER_NUM_TUBES] = {false, false, false, false, false};
unsigned long dispenserDroppedCount = 0;
unsigned long dispenserLastLdrPrintMs = 0;

int readDispenserLDR() {
  long sum = 0;
  for (int i = 0; i < DISPENSER_LDR_SAMPLES; i++) {
    sum += analogRead(DISPENSER_LDR_PIN);
    delay(3);
  }
  return (int)(sum / DISPENSER_LDR_SAMPLES);
}

bool dispenserBallPresentFromLdr(int ldr) {
  return ldr < DISPENSER_LDR_BALL_PRESENT_MAX;
}

bool dispenserNoBallFromLdr(int ldr) {
  return ldr > DISPENSER_LDR_NO_BALL_MIN;
}

void printDispenserLDR() {
  int ldr = readDispenserLDR();
  Serial.print("LDR,");
  Serial.print(ldr);
  Serial.print(",");
  if (dispenserBallPresentFromLdr(ldr)) {
    Serial.println("BALL");
  } else if (dispenserNoBallFromLdr(ldr)) {
    Serial.println("NO_BALL");
  } else {
    Serial.println("UNKNOWN");
  }
}

void writeDispenserAngle(int angle) {
  dispenserCurrentAngle = constrain(angle, 0, 180);
  if (!dispenserServoAttached) {
    dispenserServoAttached = ledcAttach(DISPENSER_SERVO_PIN,
                                        DISPENSER_SERVO_FREQ_HZ,
                                        DISPENSER_SERVO_PWM_RESOLUTION);
  }

  int pulseUs = map(dispenserCurrentAngle,
                    0,
                    180,
                    DISPENSER_SERVO_MIN_US,
                    DISPENSER_SERVO_MAX_US);
  uint32_t duty = ((uint32_t)pulseUs * (1UL << DISPENSER_SERVO_PWM_RESOLUTION)) /
                  DISPENSER_SERVO_PERIOD_US;
  ledcWrite(DISPENSER_SERVO_PIN, duty);
}

void moveDispenserCautiousTo(int target, int stepDelayMs) {
  target = constrain(target, 0, 180);
  while (dispenserCurrentAngle != target) {
    dispenserCurrentAngle += (target > dispenserCurrentAngle) ? 1 : -1;
    writeDispenserAngle(dispenserCurrentAngle);
    delay(stepDelayMs);
  }
  delay(DISPENSER_POSITION_SETTLE_MS);
}

void moveDispenserFastThenCautiousTo(int target) {
  target = constrain(target, 0, 180);
  int distance = abs(target - dispenserCurrentAngle);

  if (distance > DISPENSER_FAST_FINAL_APPROACH_DEG) {
    int dir = (target > dispenserCurrentAngle) ? 1 : -1;
    int nearTarget = target - (dir * DISPENSER_FAST_FINAL_APPROACH_DEG);
    writeDispenserAngle(nearTarget);
    delay(DISPENSER_FAST_SETTLE_MS);
  }

  moveDispenserCautiousTo(target, DISPENSER_CAUTIOUS_STEP_DELAY_MS);
}

void sweepDispenserServo(int startAngle, int endAngle, int stepDelayMs) {
  moveDispenserFastThenCautiousTo(startAngle);
  moveDispenserCautiousTo(endAngle, stepDelayMs);
}

int readDispenserLdrAtCheckPosition() {
  moveDispenserFastThenCautiousTo(DISPENSER_LDR_CHECK_ANGLE);
  delay(DISPENSER_LDR_SETTLE_MS);
  int ldr = readDispenserLDR();
  Serial.print("LDR_CHECK,");
  Serial.print(ldr);
  Serial.print(",");
  if (dispenserBallPresentFromLdr(ldr)) {
    Serial.println("BALL");
  } else if (dispenserNoBallFromLdr(ldr)) {
    Serial.println("NO_BALL");
  } else {
    Serial.println("UNKNOWN");
  }
  return ldr;
}

bool pickupFromDispenserTube(int tubeIndex) {
  Serial.print("PICKUP,");
  Serial.print(DISPENSER_TUBE_NAMES[tubeIndex]);
  Serial.print(",");
  Serial.print(DISPENSER_TUBE_START[tubeIndex]);
  Serial.print("-");
  Serial.println(DISPENSER_TUBE_END[tubeIndex]);

  sweepDispenserServo(DISPENSER_TUBE_START[tubeIndex],
                      DISPENSER_TUBE_END[tubeIndex],
                      DISPENSER_TUBE_SWEEP_DELAY_MS);

  int ldr = readDispenserLdrAtCheckPosition();
  return dispenserBallPresentFromLdr(ldr);
}

bool dropDispenserBallOnce() {
  Serial.println("DROP,BEGIN");
  sweepDispenserServo(DISPENSER_DROP_START_ANGLE,
                      DISPENSER_DROP_END_ANGLE,
                      DISPENSER_DROP_SWEEP_DELAY_MS);

  int ldr = readDispenserLdrAtCheckPosition();
  if (dispenserNoBallFromLdr(ldr)) {
    Serial.println("DROP,SUCCESS");
    return true;
  }

  Serial.println("DROP,STILL_PRESENT");
  return false;
}

bool dropDispenserBallWithRetry() {
  for (int attempt = 1; attempt <= DISPENSER_DROP_RETRY_MAX; attempt++) {
    Serial.print("DROP_ATTEMPT,");
    Serial.println(attempt);
    if (dropDispenserBallOnce()) {
      dispenserDroppedCount++;
      Serial.print("TOTAL_DROPPED,");
      Serial.println(dispenserDroppedCount);
      return true;
    }
  }

  Serial.println("DROP,FAILED");
  return false;
}

void printDispenserStatus() {
  Serial.print("STATUS,dropped=");
  Serial.print(dispenserDroppedCount);
  Serial.print(",empty=[");
  for (int i = 0; i < DISPENSER_NUM_TUBES; i++) {
    Serial.print(DISPENSER_TUBE_NAMES[i]);
    Serial.print(":");
    Serial.print(dispenserTubeEmpty[i] ? "1" : "0");
    if (i < DISPENSER_NUM_TUBES - 1) Serial.print(",");
  }
  Serial.println("]");
}

void printBoardStatus(const char *prefix) {
  Serial.print(prefix);
  Serial.print(",");
  Serial.print(FW_VERSION);
  Serial.print(",mode=");
  Serial.print(swerveModeName());
  Serial.print(",dropped=");
  Serial.print(dispenserDroppedCount);
  Serial.print(",disp_angle=");
  Serial.print(dispenserCurrentAngle);
  Serial.print(",disp_pwm=");
  Serial.print(dispenserServoAttached ? "1" : "0");
  Serial.print(",empty=[");
  for (int i = 0; i < DISPENSER_NUM_TUBES; i++) {
    Serial.print(DISPENSER_TUBE_NAMES[i]);
    Serial.print(":");
    Serial.print(dispenserTubeEmpty[i] ? "1" : "0");
    if (i < DISPENSER_NUM_TUBES - 1) Serial.print(",");
  }
  Serial.println("]");
}

void resetDispenserTubes(const char *ackLabel = "ACK,TUBE_RESET") {
  for (int i = 0; i < DISPENSER_NUM_TUBES; i++) {
    dispenserTubeEmpty[i] = false;
  }
  Serial.println(ackLabel);
  printDispenserStatus();
}
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
void loop() {
  if (Serial.available()) {
    String input = Serial.readStringUntil('\n');
    input.trim();
    if (input.length() > 0) handleCommand(input);
  }

  updateServos();
  updateDispenser();
  delay(LOOP_DELAY_MS);
}

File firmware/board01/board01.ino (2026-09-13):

#include <Wire.h>
#include <SPI.h>
#include <ESP32Servo.h>
#include <math.h>
#include <VL53L1X.h>

#include <Adafruit_LSM6DSOX.h>
#include <Adafruit_LIS3MDL.h>
#include <Adafruit_Sensor.h>
#include <Adafruit_GFX.h>
#include <Adafruit_SSD1306.h>


#define SERIAL_BAUD 921600
#define SERIAL_TIMEOUT_MS 20
#define FW_VERSION "board01_final_v4"

#define I2C_SDA 21
#define I2C_SCL 22
#define I2C_CLOCK_HZ 100000

#define ENC_SCK  18
#define ENC_MISO 19
#define ENC_MOSI 23

#define ENC_CS0  5
#define ENC_CS1  4
#define ENC_CS2  33
#define ENC_CS3  32

#define TOF1_XSHUT 13
#define TOF2_XSHUT 14
#define TOF3_XSHUT 16
#define TOF4_XSHUT 17
#define TOF5_XSHUT 25
#define TOF6_XSHUT 26
#define TOF7_XSHUT 27

#define SG90_SERVO_PIN 15
#define SG90_SERVO_FREQ_HZ 50
#define SG90_SERVO_MIN_US 500
#define SG90_SERVO_MAX_US 2500
#define SG90_INITIAL_ANGLE 180

#define SCREEN_WIDTH 128
#define SCREEN_HEIGHT 64
#define OLED_RESET -1
#define OLED_ADDR 0x3C

const int NUM_ENCODERS = 4;
const int NUM_TOF = 7;

const int CS_PINS[NUM_ENCODERS] = {ENC_CS0, ENC_CS1, ENC_CS2, ENC_CS3};
const int TOF_XSHUT_PINS[NUM_TOF] = {
  TOF1_XSHUT,
  TOF2_XSHUT,
  TOF3_XSHUT,
  TOF4_XSHUT,
  TOF5_XSHUT,
  TOF6_XSHUT,
  TOF7_XSHUT
};

const uint8_t TOF_ADDRESSES[NUM_TOF] = {
  0x30,
  0x31,
  0x32,
  0x33,
  0x34,
  0x35,
  0x36
};

const char *TOF_LABELS[NUM_TOF] = {
  "FRS",
  "BRS",
  "BLS",
  "FLF",
  "FLS",
  "CAM",
  "FRF"
};

const unsigned long RPM_INTERVAL_MS = 50;
const unsigned long TOF_INTERVAL_MS = 100;
const unsigned long IMU_INTERVAL_MS = 20;

Servo sg90Servo;
int sg90CurrentAngle = SG90_INITIAL_ANGLE;

const float MAX_REASONABLE_RPM = 500.0f;
const float RPM_DEADBAND = 1.0f;
const float RPM_SMOOTH_ALPHA = 0.35f;
const float MAX_SINGLE_SAMPLE_JUMP = 250.0f;
const uint16_t TOF_VALID_MIN_MM = 20;
const uint16_t TOF_VALID_MAX_MM = 2500;
const uint16_t TOF_MAX_STEP_PER_READ_MM = 80;
const int TOF_MEDIAN_WINDOW = 5;
const uint16_t TOF_INIT_TIMEOUT_MS = 200;
const uint16_t TOF_RUNTIME_TIMEOUT_MS = 60;
const uint8_t TOF_MAX_CONSECUTIVE_TIMEOUTS = 5;

Adafruit_LSM6DSOX lsm6dsox;
Adafruit_LIS3MDL lis3mdl;
Adafruit_SSD1306 display(SCREEN_WIDTH, SCREEN_HEIGHT, &Wire, OLED_RESET);
VL53L1X tof[NUM_TOF];

bool lsmOK = false;
bool magOK = false;
bool oledOK = false;
bool tofOK[NUM_TOF] = {false, false, false, false, false, false, false};
bool tofTimeout[NUM_TOF] = {false, false, false, false, false, false, false};
uint8_t tofConsecutiveTimeouts[NUM_TOF] = {0, 0, 0, 0, 0, 0, 0};

unsigned long lastRpmMs = 0;
unsigned long lastTofMs = 0;
unsigned long lastImuMs = 0;

float lastAngle[NUM_ENCODERS] = {0, 0, 0, 0};
float wheelRpm[NUM_ENCODERS] = {0, 0, 0, 0};
uint16_t tofRawMm[NUM_TOF] = {0, 0, 0, 0, 0, 0, 0};
uint16_t tofMm[NUM_TOF] = {0, 0, 0, 0, 0, 0, 0};
uint16_t tofSamplesMm[NUM_TOF][TOF_MEDIAN_WINDOW] = {
  {0, 0, 0, 0, 0},
  {0, 0, 0, 0, 0},
  {0, 0, 0, 0, 0},
  {0, 0, 0, 0, 0},
  {0, 0, 0, 0, 0},
  {0, 0, 0, 0, 0},
  {0, 0, 0, 0, 0}
};
uint8_t tofSampleIndex[NUM_TOF] = {0, 0, 0, 0, 0, 0, 0};
uint8_t tofSampleCount[NUM_TOF] = {0, 0, 0, 0, 0, 0, 0};
bool tofStableValid[NUM_TOF] = {false, false, false, false, false, false, false};

unsigned long greenCount = 0;
unsigned long blueCount = 0;
unsigned long redCount = 0;
unsigned long totalCount = 0;

enum OledScreen {
  OLED_SCREEN_TEAM,
  OLED_SCREEN_COUNTERS
};

OledScreen currentOledScreen = OLED_SCREEN_TEAM;

void setupOLED();
void setupOLED(bool playAnimation);
void restoreCurrentOledScreen();

int countOkTofSensors() {
  int ok = 0;
  for (int i = 0; i < NUM_TOF; i++) {
    if (tofOK[i]) ok++;
  }
  return ok;
}

void printBoardStatus(const char *prefix) {
  Serial.print(prefix);
  Serial.print(",BOARD01_FINAL,");
  Serial.print(FW_VERSION);
  Serial.print(",tof=");
  Serial.print(countOkTofSensors());
  Serial.print("/");
  Serial.print(NUM_TOF);
  Serial.print(",lsm=");
  Serial.print(lsmOK ? "1" : "0");
  Serial.print(",mag=");
  Serial.print(magOK ? "1" : "0");
  Serial.print(",oled=");
  Serial.print(oledOK ? "1" : "0");
  Serial.print(",enc=");
  Serial.print(NUM_ENCODERS);
  Serial.print(",sg90=");
  Serial.println(sg90CurrentAngle);
}


uint16_t readAS5048RawNoTransaction(int csPin) {
  digitalWrite(csPin, LOW);
  delayMicroseconds(2);
  uint16_t value = SPI.transfer16(0xFFFF);
  digitalWrite(csPin, HIGH);
  return value & 0x3FFF;
}

uint16_t readAS5048Raw(int csPin) {
  SPI.beginTransaction(SPISettings(4000000, MSBFIRST, SPI_MODE1));
  uint16_t value = readAS5048RawNoTransaction(csPin);
  SPI.endTransaction();
  return value;
}


void readAllEncodersRawDeg(float outDeg[NUM_ENCODERS]) {
  SPI.beginTransaction(SPISettings(4000000, MSBFIRST, SPI_MODE1));
  for (int i = 0; i < NUM_ENCODERS; i++) {
    outDeg[i] = rawToDeg(readAS5048RawNoTransaction(CS_PINS[i]));
  }
  SPI.endTransaction();
}

float rawToDeg(uint16_t raw) {
  return (raw * 360.0f) / 16383.0f;
}

float angleDelta(float prev, float curr) {
  float d = curr - prev;
  while (d > 180.0f) d -= 360.0f;
  while (d < -180.0f) d += 360.0f;
  return d;
}

bool validTofDistance(uint16_t mm) {
  return mm >= TOF_VALID_MIN_MM && mm <= TOF_VALID_MAX_MM;
}

uint16_t medianTofForSensor(int sensor) {
  uint16_t sorted[TOF_MEDIAN_WINDOW];
  uint8_t count = tofSampleCount[sensor];

  for (uint8_t i = 0; i < count; i++) {
    sorted[i] = tofSamplesMm[sensor][i];
  }

  for (uint8_t i = 1; i < count; i++) {
    uint16_t value = sorted[i];
    int j = i - 1;
    while (j >= 0 && sorted[j] > value) {
      sorted[j + 1] = sorted[j];
      j--;
    }
    sorted[j + 1] = value;
  }

  return sorted[count / 2];
}

uint16_t limitTofStep(uint16_t current, uint16_t target) {
  if (target > current) {
    uint16_t delta = target - current;
    return current + min(delta, TOF_MAX_STEP_PER_READ_MM);
  }

  uint16_t delta = current - target;
  return current - min(delta, TOF_MAX_STEP_PER_READ_MM);
}

void disableTofSensor(int sensor, const char *reason) {
  if (sensor < 0 || sensor >= NUM_TOF) return;

  tofOK[sensor] = false;
  tofTimeout[sensor] = false;
  tofRawMm[sensor] = 0;
  tofMm[sensor] = 0;
  tofSampleIndex[sensor] = 0;
  tofSampleCount[sensor] = 0;
  tofStableValid[sensor] = false;
  tofConsecutiveTimeouts[sensor] = 0;

  pinMode(TOF_XSHUT_PINS[sensor], OUTPUT);
  digitalWrite(TOF_XSHUT_PINS[sensor], LOW);

  Serial.print("WARN,TOF_DISABLED,");
  Serial.print(sensor);
  Serial.print(",");
  Serial.print(TOF_LABELS[sensor]);
  Serial.print(",");
  Serial.println(reason);
}

void setupEncoders() {
  SPI.begin(ENC_SCK, ENC_MISO, ENC_MOSI);

  for (int i = 0; i < NUM_ENCODERS; i++) {
    pinMode(CS_PINS[i], OUTPUT);
    digitalWrite(CS_PINS[i], HIGH);
  }

  for (int i = 0; i < NUM_ENCODERS; i++) {
    lastAngle[i] = rawToDeg(readAS5048Raw(CS_PINS[i]));
  }

  lastRpmMs = millis();
}
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

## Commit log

2026-09-14 Combine hardware and software with CAD assets and Git LFS tracking
    [Argus_Omnimotus_Master_Multibody.SLDPRT, components.csv]
2026-09-14 Prepare repository for public release
    [Argus_Omnimotus_Master_Multibody.SLDPRT, BOM.csv, components.csv]
2026-09-15 Update BOM.csv to correct steel rod quantity
    [BOM.csv]
